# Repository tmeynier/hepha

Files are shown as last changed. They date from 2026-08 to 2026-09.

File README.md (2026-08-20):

# Hepha

TODO:

- CAD of camera holding and drawers = should finish drawers
- Check ACT policy running a lot faster
- Run flow matching
- Run VLA policy
- Try RL

"I used to fork LeRobot repository but with AI I can easily create a new repo 
with only features of LeRobot that I am interested in"

This document presents *Hepha*, a robotics project where I build and train a 
bimanual robot moving in a warehouse environment.

GIFS of the robot moving in the warehouse

GIFS of the robot moving in the greenhouse

The goals of the project are:

* Become familiar with the technologies and models used in general-purpose
  robotics (such as humanoid robots).
* Explore the challenges and current research directions in general-purpose
  robotics.
* Serve as a tutorial for readers interested in building their own robots. I
deliberately document my trials and errors to help readers understand the
challenges involved and develop an intuition for each SOTA model.

The robot consists of two parts: (1) an upper body composed of a bimanual
robot mounted on a CNC gantry system, and (2) a mobile base, similar to an
Autonomous Mobile Robot (AMR), that enables the robot to navigate throughout
the warehouse environment.

GIFS of the real upper body

GIFS of the mobile base

Most of this document focuses on the robot's upper body, covering the complete
development pipeline: mechanical design in Fusion360, 3D printing, simulation in 
Mujoco and Isaac Sim, demonstration recording for Behavioral Cloning (BC), 
policy training, RL fine-tuning, and closed-loop validation.

I also briefly discuss the robot's autonomous navigation in the warehouse,
coordination between multiple robots, and their integration into a broader
enterprise architecture. In this architecture, the robots, the ERP system, and
the Retrieval-Augmented Generation (RAG) pipeline are connected to a central
coordinator, allowing operators to control an entire fleet of robots from a
single chat interface while continuously updating the ERP and RAG according to 
the robots' actions.

For the robot's upper body, the task is the following:

> *Given a user's request, place or remove a foam cube in the correct warehouse
> drawer.*
>
> **Examples**
>
> - *Place the blue cube from the storage bin into drawer 5.*
> - *Remove the red cube from drawer 2.*
 
The task deliberately captures many of the challenges found in real-world
warehouse environments. Retrieving or placing a foam cube in a drawer
resembles storing or picking products while updating an ERP system. The same
perception, planning, and manipulation pipeline also applies to retail
(stocking supermarket shelves) and agriculture (harvesting crops in a
greenhouse). Although simplified, the techniques explored in this project
generalize to a wide range of robotic applications.

Finally, I share my perspective on the field based on my experience, discussing
the research directions I find the most promising and the challenges that still
remain.

This document was polished using AI, but I have intentionally kept
the writing simple and close to my own words.

This is not a research or survey paper, so please forgive the lack of
formalities. It is a practical project report about what I love doing.

**PS:** I made a summary video of the project here:
**TODO: Link to video**

**PS:** The project is called *Hepha*, after **Hephaestus**, the Greek god of
craftsmanship, invention, and technology.

## Table of Contents

1. [Brief Words About Me](#brief-words-about-me)
2. [Before Starting](#before-starting)
3. [Why General Purpose Robotics Is Hard](#why-general-purpose-robotics-is-hard)
4. [Pipeline Overview](#pipeline-overview)
5. [Step 1: CAD Modeling](#step-1-cad-modeling)
6. [Step 2: Simulation And Benchmark
   Policy](#step-2-simulation-and-benchmark-policy)
7. [Step 3: Real World Fine Tuning](#step-3-real-world-fine-tuning)
8. [Conclusion](#conclusion)
9. [Going Further](#going-further)
10. [Perspective](#perspective)
11. [References](#references)
12. [Citation](#citation)

## Brief Words About Me

I am a passionate machine learning engineer from Switzerland.

For the past five years I have played with robotics: Arduino, Raspberry Pi, CAD
software, CNC systems including 3D printers, servo motors and stepper motors,
actuators, radios, GSM modules, ... and many more.

I then used my machine learning background to train my own policies on the cloud and
make hardware move intelligently.

And it is so much fun, you will see.

## Before Starting

If you don't have experience in robotics yet, I recommend you to have a look at
the LeRobot project.

[LeRobot](https://huggingface.co/lerobot) is an open source project from Hugging 
Face that helps you build a 3D printed robot and run a machine learning policy on it.

**TODO:** add a GIF of my own LeRobot robot.

I also encourage you to create your own policies in LeRobot. A custom policy
that I really liked is the [DOT
policy](https://github.com/IliaLarchenko/dot_policy) from Ilia Larchenko. 

If you want to stay on your computer, without a 3D printed robot, you can also
train policies in virtual tasks, for example the PushT task trained in a Gym
environment.

**TODO:** add GIF of my PushT policy demo.

LeRobot is an amazing open source project. It has evolved from a small 
imitation learning library into one of the most complete open-source robotics 
frameworks. It contains implementations of most of the leading model 
architectures in imitation learning and reinforcement learning, ranging from ACT and 
Diffusion Policy to recent open-source Vision-Language-Action (VLA) and JEPA (Joint 
Embedding Predictive Architecture) family models.

I will mention and use some of these models: ACT, Diffusion models, VLAs, 
and V-JEPA 2. I will reuse LeRobot's dataset schema and some of its model
architectures. However, for learning purposes, I will not use the
low-code approach provided by LeRobot and instead build the models myself. 
I believe that building things yourself is one of the best ways to develop intuition 
and truly understand how things work.

### Prerequisites For This Project

1. **CAD**: familiarity with CAD software such as Fusion360, FreeCAD or
   SolidWorks.
2. **Simulation engines**: MuJoCo from DeepMind, Isaac Sim from Nvidia.
3. **ML knowledge**: imitation learning (particularly behavior cloning)
   and reinforcement learning.

## Why General Purpose Robotics Is Hard

Let me be clear: no, you cannot simply plug Claude Code, Gemini or ChatGPT into
humanoid hardware and get a fully autonomous human-looking robot.

LLMs are very good at text, but the physical world is very different from text,
and a lot more complex.

To get a sense of it, first note that for LLMs the amount of high quality
training data available is incredibly large: the internet, billions of text
examples. The space of English text to predict is relatively small: a few
thousand common words or tokens.

General purpose robotics is very different.

The inputs are images, which are much more complex to analyze than text. Possibly 
other sensor data: touch data, lidar data for depth, text, or audio
commands from a human. Basically, any input your brain receives from your body.

The output is a set of servo joint coordinates, meaning actions of the robot in
the physical world, and potentially voice if the robot should speak.

Unlike for LLMs, the amount of high quality robotics data, meaning observation data
and ground truth action pairs, is very limited.

Also unlike LLMs, where the prediction space is rather small and discrete, the
action space in robotics is continuous, and immense.

As a result, even the best LLMs will not perform well if you simply plug them
into your robot. It is also going to be very slow.

Actually, the autoregressive prediction objective that made LLMs so successful may 
not be the best way to learn representations of the physical world. Predicting every 
pixel of a future image (or reconstructing an entire image, as in an autoencoder) is 
an extremely difficult task, and much of that visual detail is irrelevant for 
decision making. 

Instead we need models capable of understanding the mapping from world 
observations to actions, and vis-versa. Models capable of learning a coherent 
embedding of the world - called *world models*. Recent work in this direction 
includes Yann LeCun's JEPA model architecture family. The idea is to predict a 
high-level representation (embedding) of missing or future information rather than 
the pixels themselves. A typical JEPA consists of:

- **Context encoder** $f_\theta$: encodes the observed part of the input.
- **Target encoder** $g_\xi$: encodes the target (for example, a future frame, a masked region, or another view).
- **Predictor** $h_\phi$: predicts the target embedding from the context embedding.

Rather than minimizing pixel reconstruction error, the model is trained so that

$$
h_\phi(f_\theta(x_{\text{context}})) \approx g_\xi(x_{\text{target}})
$$

This objective encourages the model to capture the semantic information needed to 
understand and predict the world, instead of spending capacity on reconstructing 
fine-grained visual details. LeCun recently founded [AMI Labs](https://amilabs.xyz/), 
a startup focused exactly on developing these next-generation world models.

To summarize, two important challenges of general purpose robotics are:

1. **Data**: high quality ground truth observation-action pairs.
2. **Adequate models**: models capable of understanding the world and the
surrounding physics, while still being very fast at inference. They should 
support inference at roughly 30–50 Hz, meaning the policy produces a 
new action every 20–33 ms. This is fast enough for smooth manipulation and 
good responsiveness. Slower models reduce the robot's ability to react quickly to 
changes in the environment.

### The Data Challenge

Data primarily comes from three sources:

- **Internet data** (text, images, and videos): used to train large foundation 
models on billions of examples. These models learn general-purpose representations 
of the world, although they are not optimized for a specific robot task. Their 
representations can later be adapted to robotics through models such as SmolVLA, or 
by generating synthetic robot data with systems such 
as [FLUX.3 + Mimic](https://bfl.ai/blog/flux-3-mimic).

- **Simulation data**: generated in physics simulators or even video games (FPV 
video games can be used to train humanoid robots). Simulation allows millions of 
episodes to be generated safely, quickly, and at low cost. The challenge is 
the *sim-to-real gap*: no simulator perfectly reproduces the real world. Differences 
often prevent a policy trained purely in simulation from working on a real robot. 
NVIDIA developed (Isaac Sim)[https://developer.nvidia.com/isaac] specifically 
to narrow this gap by providing highly realistic, GPU-accelerated simulations.
(MuJoCo)[https://mujoco.org] (developed by Deep Mind) serves a 
similar purpose and is widely used in robotics research. While less visually 
realistic than Isaac Sim, it is computationally much more efficient and can even run 
on CPUs, making it ideal for rapid experimentation.

- **Real robot episodes**: demonstrations collected by *teleoperating* a robot. 
During teleoperation, the robot records a sequence of observations together with the 
ground-truth actions performed by the human operator. These observation-action pairs 
form the demonstrations used for imitation learning. One common setup is a 
*leader–follower* system: the human moves a leader robot, while the follower 
robot mirrors its movements and records the data. Human can control the robot with 
game controller, a SpaceMouse, VR headsets, motion-capture gloves (e.g. [Mimic 
  Robotics](https://www.mimicrobotics.com/)), or leader–follower robot 
arms. Full-body teleoperation suits are even being developed to 
control an entire humanoid robot. Real robot demonstrations provide the 
highest-quality supervision because they capture the true dynamics, sensor noise, 
and physical interactions of the target robot. However, collecting them is slow, 
expensive, and difficult to scale to millions of episodes.

```mermaid
flowchart TD

%% =========================
%% Data Sources
%% =========================
A1["🌐 Internet"]
A2["🎮 Simulation Data"]
A3["🤖 Real Robot Episodes"]

%% =========================
%% Base Policy
%% =========================
B["Train / Fine-Tune<br/>Base Policy"]

%% =========================
%% RL Fine-Tuning
%% =========================
C["RL Fine-Tuning<br/>in Simulation Environment"]

%% =========================
%% Final Policy
%% =========================
D["Final Robot Policy"]

A1 --> B
A2 --> B
A3 --> B

B --> C
C --> D
```

## ACT advantage-weighted regression (AWR)

Hepha keeps upstream LeRobot ACT as the actor and provides a separate
`hepha_act_awr` extension. It follows ordered AWR policy iteration: collect
trajectories, fit the value head, freeze it and materialize advantages, fit ACT
with those immutable weights, collect new trajectories, merge them into the replay
dataset, and repeat. Value and actor regression never run in the same optimizer step.

For each replay transition, Hepha computes the Monte-Carlo target
`G_t = r_t + gamma * G_(t+1)`, then `A_t = G_t - V(s_t)`. Advantages are
standardized once over the replay dataset and converted to fixed weights
`min(exp(normalized_A_t / beta), awr_max_weight)`. ACT minimizes its usual per-sample
L1-plus-KL loss multiplied by that weight; transitions are still sampled uniformly.

Install the updated local entry points after pulling the repository:

```bash
.venv/bin/python -m pip install -e .
```

Collect closed-loop rollouts from the original ACT policy. All episodes are retained,
including failures, and are stored as a normal LeRobot dataset with `next.reward`
and `next.done`:

```bash
.venv/bin/hepha-awr-record models/hepha_act_200 \
  --repo-id tmeynier/hepha_act_awr_rollouts \
  --root datasets/hepha_act_awr_rollouts \
  --episodes 100 \
  --episode-seconds 100 \
  --seed-start 30000 \
  --device mps \
  --n-action-steps 1 \
  --temporal-ensemble-coeff 0.01 \
  --domain-randomization-scale 0 \
  --push-to-hub \
  --overwrite
```

The per-transition rewards are:

- `-0.001` every control step.
- `+1` the first time the selected drawer reaches 40 mm opening.
- `+3` the first time the elevated cube is stably held by both opposing pads of
  one gripper.
- `+2` the first time the cube center enters the selected drawer.
- `+5` at the terminal step when the cube is inside and the selected drawer is
  at most 5 mm open.
- `-2` when robot contact with an external object begins. Gripper/cube contact
  and selected-drawer-handle contact are allowed.
- `-0.5` when contact with the selected drawer body (excluding its handle) begins.
- `-1` when robot/floor contact begins.
- `-3` when a previously elevated cube begins touching the floor.
- `-2` when left-arm/right-arm contact begins, including the fingers.

Sustained contacts are charged once on contact onset, rather than once per frame.

Convert the original ACT checkpoint once. This copies every ACT weight exactly and
randomly initializes only the new value head:

```bash
.venv/bin/hepha-awr-init \
  models/hepha_act_200 \
  models/hepha_act_awr_init \
  --overwrite
```

Fit only the value head. ACT parameters and BatchNorm buffers remain frozen:

```bash
.venv/bin/hepha-train \
  --repo-id tmeynier/hepha_act_awr_rollouts \
  --root datasets/hepha_act_awr_rollouts \
  --policy-type hepha_act_awr \
  --policy-path models/hepha_act_awr_init \
  --output-dir outputs/hepha_act_awr_value_i0 \
  --job-name hepha_act_awr_value_i0 \
  --device cuda \
  --steps 20000 \
  --batch-size 8 \
  --num-workers 4 \
  --wandb \
  --policy-repo-id tmeynier/hepha_act_awr_value_i0 \
  -- \
  --dataset.eval_split=0.1 \
  --eval_steps=2000 \
  --policy.awr_stage=value \
  --policy.awr_discount=0.999 \
  --policy.awr_beta=1.0 \
  --policy.awr_max_weight=20 \
  --policy.value_optimizer_lr=0.0001 \
  --wandb.project=hepha
```

Freeze that checkpoint and calculate one immutable advantage and weight per replay
frame:

```bash
.venv/bin/hepha-awr-advantages \
  outputs/hepha_act_awr_value_i0/checkpoints/last/pretrained_model \
  --repo-id tmeynier/hepha_act_awr_rollouts \
  --root datasets/hepha_act_awr_rollouts \
  --output awr/iteration-000/advantages.parquet \
  --device cuda \
  --batch-size 32 \
  --num-workers 4 \
  --push-to-hub \
  --hub-repo-id tmeynier/hepha_act_awr_advantages_i0 \
  --overwrite
```

The rollout dataset, fitted value checkpoint, frozen advantage table, and actor
checkpoint are therefore all stored in separate Hugging Face repositories. A new
Pod can resume from the uploaded artifacts without access to an earlier Pod's disk.

Fit only ACT using the fixed weights. The value head remains frozen:

```bash
.venv/bin/hepha-train \
  --repo-id tmeynier/hepha_act_awr_rollouts \
  --root datasets/hepha_act_awr_rollouts \
  --policy-type hepha_act_awr \
  --policy-path outputs/hepha_act_awr_value_i0/checkpoints/last/pretrained_model \
  --output-dir outputs/hepha_act_awr_actor_i0 \
  --job-name hepha_act_awr_actor_i0 \
  --device cuda \
  --steps 100000 \
  --batch-size 8 \
  --num-workers 4 \
  --wandb \
  --policy-repo-id tmeynier/hepha_act_awr_i0 \
  -- \
  --dataset.eval_split=0.1 \
  --eval_steps=10000 \
  --policy.awr_stage=actor \
  --policy.awr_advantage_path=awr/iteration-000/advantages.parquet \
  --wandb.project=hepha
```

For the next iteration, collect fresh trajectories from the updated actor:

```bash
.venv/bin/hepha-awr-record \
  outputs/hepha_act_awr_actor_i0/checkpoints/last/pretrained_model \
  --repo-id tmeynier/hepha_act_awr_rollouts_i1 \
  --root datasets/hepha_act_awr_rollouts_i1 \
  --episodes 100 \
  --episode-seconds 100 \
  --seed-start 40000 \
  --device mps \
  --n-action-steps 1 \
  --temporal-ensemble-coeff 0.01 \
  --domain-randomization-scale 0 \
  --push-to-hub \
  --overwrite
```

Append them to a new cumulative replay dataset; the two inputs remain unchanged:

```bash
.venv/bin/hepha-awr-merge \
  --replay-repo-id tmeynier/hepha_act_awr_rollouts \
  --replay-root datasets/hepha_act_awr_rollouts \
  --new-repo-id tmeynier/hepha_act_awr_rollouts_i1 \
  --new-root datasets/hepha_act_awr_rollouts_i1 \
  --repo-id tmeynier/hepha_act_awr_replay_i1 \
  --root datasets/hepha_act_awr_replay_i1 \
  --push-to-hub \
  --overwrite
```

Run the same value, advantage, and actor stages using the iteration-1 actor as
`--policy-path`, the merged replay dataset, and new output paths. Every iteration
recomputes all returns and advantages; an old advantage file cannot silently be
used with a different replay repository.

W&B value runs report `value_loss`, `value_mean`, `return_mean`, and
`value_error_mean`. Actor runs report `actor_loss`, `advantage_mean`,
`awr_weight_mean`, and `awr_weight_max` for training and held-out evaluation.

All three sources of data are generally used together to build a strong base 
policy.

Once the base policy is trained, Isaac Sim and Mujoco provide an environment 
for RL fine-tuning. The robot can practice millions of additional interactions 
while optimizing task-specific reward functions. Examples of rewarded actions: 
successfully grasping an object, avoiding collisions, minimizing energy consumption, 
maintaining balance (for humanoids), etc.

### The Model Challenge

The research community is still divided on what the best approach for learning
world models will be.

Some believe that scaling data, model size, and compute will solve the problem. 
Of course this is the narrative of some big companies like NVIDIA, for obvious 
business reasons.

Others, including Yann LeCun, argue that simply scaling data and compute may
not be sufficient. Instead, they advocate architectures inspired by some
aspects of human cognition. Before performing an action, humans typically
reason and plan using an internal representation of the world built through
years of experience. We can mentally simulate the consequences of different
actions without physically executing them. Once a plan has been chosen,
lower-level motor control—what we often call *muscle memory*—executes it
rapidly and with little conscious reasoning.

This suggests that different levels of intelligence require different
computational mechanisms. High-level decision making involves reasoning,
planning, and predicting future outcomes, while low-level control is more
mechanical, closer to reflexes, and must operate at very high frequency.

For readers interested in this perspective, I highly recommend Yann LeCun's
lecture *A Path Towards Autonomous Machine Intelligence*. In particular,
Figure 1 provides an excellent illustration of this hierarchical view of
intelligence and world models.

There is unlikely to be a single path toward efficient world
models. Better architectures, larger and higher-quality datasets, and
increased compute will probably all contribute. The most successful systems
will likely combine advances in each of these areas.

In this project I experimented with a diverse set of methods to build my own 
opinion and understanding.

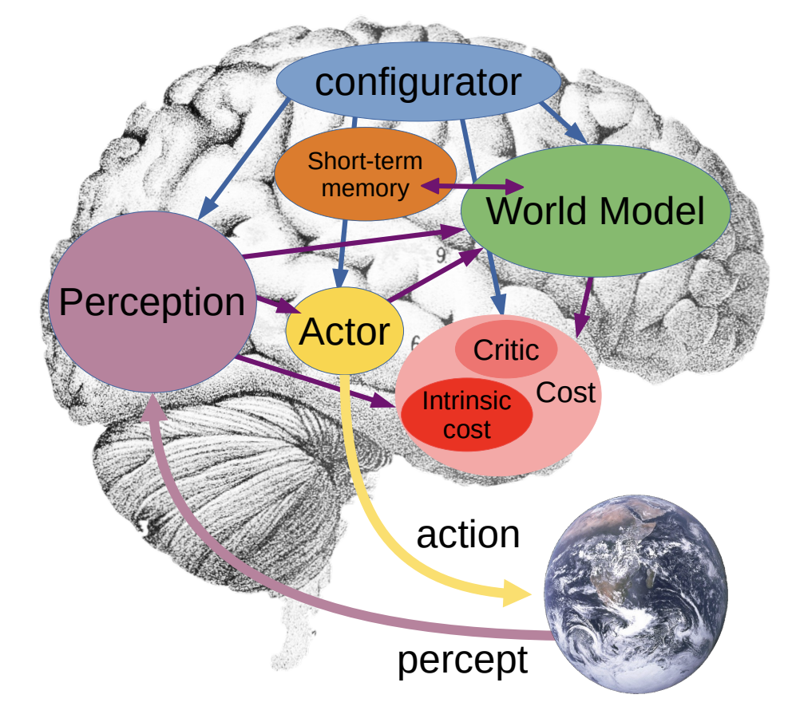
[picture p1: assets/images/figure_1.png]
Figure 1: JEPA world-model architecture


**Figure 1:** High-level architecture proposed by Yann LeCun as a foundation for
the JEPA family of world-model architectures. The perception module estimates
the current world state, the world model predicts future states under candidate
actions, the critic evaluates their expected cost, and the actor selects the
best action sequence. Short-term memory stores intermediate states, while the
configurator coordinates all modules for the current task.

## Project Pipeline

The project focuses primarily on the design and training
of the robot's upper body (the dual-arm manipulator). I will only briefly touch
on the mobile base at the end. The project pipeline is:

1. Design the robot in Fusion360.

2. Obtain a proper robot description file (URDF) from Fusion360 and use it to
   build a simulation environment (a digital twin of the real robot) in MuJoCo
   and Isaac Sim.

3. The fun part: train a base policy using imitation learning.

4. Use RL to fine-tune the base policy in the simulated environment.

Most of the work in this document focuses on step 3. Initially, all policies are
trained in MuJoCo rather than on the real robot. MuJoCo provides an excellent
playground to understand how difficult the problem really is without having to
deal with hardware issues, sensor noise, or broken parts.

Some of the intermediate steps presented here are not necessary to
obtain a working policy. I deliberately include them because they helped me
develop a much better intuition for the problem and for SOTA models.

Important concepts covered during policy training are:

* **The importance of failure recovery.** A good policy is not one that performs
  the next step well, but one that remains reliable after thousands of
  consecutive steps. Robotics is even more autoregressive than LLMs: one bad
  action at the beginning can leave the robot in a completely different state
  from the one it was trained on. Throughout the project I use *closed-loop*
  validation, where the robot executes the entire task using only the policy,
  and the final success rate is measured. Diverse data, robust models, and
  RL fine-tuning all help the policy recover from its own mistakes.

* **The challenge of embodiment.** Embodiment refers to the idea that an
  intelligent agent has a physical body through which it perceives and interacts
  with the world. ChatGPT, for example, has no body. If you connect it to a
  robot, it must learn how to control that body and interact with the
  environment. This is one of the main challenges of robotics foundation models:
  they may have been trained on many different robots, but not on *your* robot.
  Fine-tuning of the foundation model is required for the model to
  "learn" its own embodiment. I intentionally designed a robot with 15 degrees
  of freedom that does not resemble existing robots, making embodiment a relevant 
  challenge.

* **The multimodality problem.** A single observation can correspond
  to many valid actions - e.g. an object can be picked from the left or
  from the right. If the training data contains both strategies, a traditional
  regression model may predict their average—which could be an invalid action. 
  Policies should learn a distribution over possible actions given an observation,
  $p(a \mid o)$, rather than predicting a single deterministic action. Gen AI 
  can be a solution. Target distribution that have different modes.For example a 
  simple MSE would optimize to predict the mean of the data. MAE is lot better 
  than MSE. VQ-BeT avoids this by turning continuous actions into discrete tokens, much
like language models turn text into tokens.Because classification solves the 
  problem = this naturally models multiple valid behaviors.
Unlike ACT, there is no CVAE latent variable.
Unlike Diffusion Policy, there is no denoising process. Diffusion model the whole 
  distribution rather than doing point prediction.
Diffusion: "Learn how to gradually remove noise."
Flow Matching: "Learn the velocity field that transports noise into data."
Robot when predicting chunks can go left then right, left then right, .... Realt 
  Time Action Chunking with Large Models

* **The importance of planning horizon.** Predicting a chunk of future actions
  is more effective than predicting only the next action. A robot must
  understand not only where it should move, but also the intended motion,
  velocity, and trajectory. These are better captured when the model predicts a
  sequence of future actions.
The action distribution in robotics versus LLMs is very different: actions are 
  very correlated, sometimes sequence of actions that are the same, etc. Which 
  might make the model always predict the same action.

* **The importance of inference speed.** A larger model may achieve higher
  accuracy, but it is of little practical use if it cannot run at the required
  control frequency. Large models are well suited for high-level reasoning and
  long-term planning, while smaller models excel at fast, reactive control.
  Combining both often provides the best trade-off.
System 1 and system 2 from Daniel Kahneman. See Gemini Robotics paper from Google 
  or Pi0.5 from Physicall Intelligence or Gr00t model from Nvidia.
Real word manipulation and embodiment data would be great new data for LLMs.

Now the robot reaches a state that was never present in the training dataset.

The policy doesn't know what to do there.

It makes another mistake → gets even further away → makes another mistake.

This is called distribution shift or compounding errors.

Only RL can beat the expert, because it optmizes for it.

Show the pyramid of robot data to show your reasoning

Data augmentation — general umbrella term. You modify observations/actions while preserving the intended behavior: camera noise, lighting changes, object-position variations, action noise, etc.
Trajectory perturbation / demonstration perturbation — specifically perturbing expert trajectories to expose the policy to imperfect states.
Domain randomization — randomizing the simulation/environment: textures, lighting, camera pose, friction, masses, object positions, etc. Primarily useful for robustness and sim-to-real.
Noise injection — explicitly adding noise to states, observations, or actions.
Recovery data / recovery demonstrations — particularly important for BC: deliberately move the robot away from the perfect expert trajectory and provide the correct action to recover.
DAgger — goes further: run the learned policy, let it reach states that the expert dataset didn't contain, then have an expert label the correct actions for those states.

### Robot Description (Upper Body)

The robot's upper body has 15 Degrees of Freedom (DoF): three linear axes
(x, y, and z) provided by the CNC gantry, and two 6-DoF robotic arms.

The CNC gantry is equipped with closed-loop servo motors that I reused from 
another personal project. It allows the robot to move its arms between different 
work areas: closer to the collector or closer to the warehouse shelves.

**TODO:** add two images of the robot in two work position

### Task Description (Upper Body)

As mentioned earlier, the task is: 

> *Given a user's request, place or remove a foam cube in the correct warehouse
> drawer.*

The task resembles a realistic robot task in a warehouse-like environment. I call 
*warehouse-like environment* any environment composed of zones where
robots maneuver and zones where products are stored, placed, or picked from.
Examples are traditional warehouses, supermarkets, pharmacies, greenhouses, or
even vineyards.

The robot would navigate in the environment and use its arms to place
objects into storage, or remove objects from storage.

I will not discuss autonomous navigation in the warehouse-like environment, as this 
does not necessarily require a ML model. If you are curious, the real robot base for 
navigation looks like this (it should use omniwheels in some settings or 
mechanical wheels):

**TODO:** add GIFS of the robot base moving

In humanoid robot design, not using legs but an Autonomous Mobile Robot (AMR) is 
an approach also taken by [Genesis AI](https://www.genesis.ai/). It greatly 
simplifies the problem while preserving most of the robot's capabilities.

**TODO:** add GIFS of Genesis AI robot

TODO: mention about the complexity of the task: not always fetch the cube or open 
drawer with the same hand, hand collaboration, moving in the right direction with 
respect to hand 1 or 2, etc.

## Step 1: Model The Robot CAD

First, I construct the 3D model of the robot.

This is required to validate the design, 3D print the robot, and build the
simulation environment in MuJoCo and Isaac Sim.

I use [Fusion360](https://www.autodesk.com/products/fusion-360/overview).

The path to the CAD project is **TODO**.

Each component is modeled as an assembly, possibly made of several
subcomponents:

```text
hepha-robot-cad
├── base
├── cnc_x
├── cnc_y
├── shoulder_l
├── shoulder_r
├── head
├── forearm_l
├── forearm_r
├── arm_l
├── arm_r
├── wrist_l
├── wrist_r
├── hand_l
├── hand_r
├── finger_l
├── finger_r
├── storage_rack
└── storage_bin
```

The structure of the Fusion360 assembly is very important because the
requirements for 3D printing and URDF export are different.

* Rule 1 (3D printing): each physical part should be its own assembly
  (although your assembly can be nested to keep the project organized). It's
  the conventional structure used in CAD projects, as shown above.

* Rule 2 (URDF export): the assembly hierarchy must instead follow the
  robot's kinematic tree: each movable link should be represented by a
  separate assembly. For example, the left shoulder link is one assembly, the
  left upper arm another, and so on, connected by revolute or linear joints.
  I describe this structure in the next section.

Because these two hierarchies serve different purposes and are organized 
differently, I maintain two separate Fusion360 projects.

**TODO:** add GIF of the CAD.

The robot components were 3D printed and assembled, for both the leader and follower.
Since I do not have a CNC machine for the leader, I used a controller to
lead the CNC follower.

**TODO:** add GIF of the real robot with the leader and follower.

## Step 2: Build The Simulation Environment

Tell that you used IK to see if everything works in the environment.

Building a simulation environment with a digital twin of the robot is essential 
to validate the hardware and train RL policies. I will try both MuJoCo and Isaac Sim 
and compare the two.

### From CAD to URDF

To create a robot description file that can be used by simulators, I use the
Fusion360 plugin `ACDC4Robotics` to convert the CAD model into a `.urdf` file.
A `.urdf` file describes the robot: it contains not only the visual meshes of
its components, but also the joints between them, inertial properties, centers
of mass, friction parameters, and other information required to build a
realistic simulation.

To use `ACDC4Robotics`, I had to transform my original
`hepha-robot-cad` project into a new project called `hepha-robot-sim`.
You can find it at **TODO:** add path.

In the CAD project, components are organized as physical robot parts. In the
simulation project, they must instead follow the robot's kinematic tree: one
component per **link**, with exactly one body inside each link component.

```text
hepha-robot-sim
├── cnc_x_link
├── cnc_y_link
├── shoulder_l_link
├── shoulder_r_link
├── forearm_l_link
├── forearm_r_link
├── arm_l_link
├── arm_r_link
├── wrist_l_link
├── wrist_r_link
├── hand_l_link
├── hand_r_link
├── finger_l_link
├── finger_r_link
├── drawer_1_link
├── drawer_2_link
├── drawer_3_link
├── drawer_4_link
├── drawer_5_link
├── drawer_6_link
├── drawer_7_link
├── drawer_8_link
├── drawer_9_link
└── head_link
```

To create this new hierarchy, I first created an empty component for every
link. I then copied the relevant bodies into their corresponding link
components, combined them into a single body using Fusion360's `combine` tool,
and finally created the joints between the links (`revolute` or `slider`).

**TODO**: GIFS of the simulated robot

### MuJoCo

MuJoCo is one of the most widely used physics simulators in robotics research.
It is easy to install, has a relatively low learning curve, and is
computationally efficient while still providing accurate physics simulation.
Unlike Isaac Sim, MuJoCo runs well on a local machine without requiring a GPU.
Its main drawback is that it does not produce photorealistic renderings, which
can be important for vision-based robot policies (like for humanoid robots).

The `.urdf` file generated in the previous section only defines the robot's
visual meshes and joints. Since visual meshes are only used for rendering, I
also needed to define collision geometries to obtain a physically realistic
simulation.

MuJoCo's physics engine relies on simple primitive geometries (boxes, spheres,
cylinders, etc.) for collision detection, as they are much faster and more
numerically stable than arbitrary triangle meshes. For each link in my
`hepha-robot-sim` project, I therefore created a simplified `.step` file made
only of primitive boxes. I then wrote a small Python script to convert these
files into the corresponding MJCF collision geometries.

Finally, I ensured that the robot had realistic joint limits, centers of mass,
and inertia before running the simulation.

**TODO:** add path to the collision `.step` files.

**TODO:** add path to the final `.urdf` file.

**TODO:** add GIF showing the collision geometries.

### Isaac Sim

## Step 3: Base Policy Training

First, define the metrics

- importance of failure recovery: act on simplified data + importance of planning 
  horizon with act
- challenge of embodiment: explain how to fine tune the foundation model + 
  importance of inference speed

ACT simple

Foundation simple

Act random

Diffusion random

Foundation 0 random 

Foundation 1 random

With BC real robot

RL fine tuning 

Final demo

metrics: closed loop validation, achievement: grasped cube, ...

## Step 4: RL Fine Tuning

#### Collision Geometries

#### Recording Episodes In Simulation

Now that I have a somewhat realistic digital twin of the robot, I can set things
up to record virtual episodes of the robot doing the task. Three methods can be
used to record episodes in the simulated environment:

1. use a controller,
2. use a physical leader,
3. use inverse kinematics, IK.

IK allows to compute the joint movements required to place the end effector, the
robot hand with the gripper, in a target position. When used several times, it
allows to artificially create a robot movement. For example, I can decompose the
movement "grab the cube and place it into the drawer" into smaller targets:
"place the hand in grab position", "close the hand", "move the hand above the
drawer", and "open the hand".

With this technique, the overall movement of the robot is not very natural or
flexible. For example, if the cube falls out of the hand, the robot will not
re-fetch it and will continue the movement without the cube. But IK makes it
possible to create a large set of episodes, which can be used to train a
benchmark policy and fine tune it later with higher quality data.

Recording using a controller or a physical leader is on the other hand time
consuming, so I decided to use IK first to train a benchmark policy. I will use
the physical leader and controller later to fine tune the policy.

Starting from a strong benchmark policy is especially important for RL because
it dramatically reduces exploration. It allows the agent to refine an already
competent behavior instead of wasting time discovering basic skills from
scratch.

**TODO:** add GIF of episodes.

Before the start of each episode, I randomize the position and orientation of
the cube, the colors of the geometries, and add a bit of noise to the camera
position and orientation between episodes for better generalization.

Episodes are stored as a Hugging Face dataset using LeRobot's dataset format,
also used by Nvidia and many robotics companies.

#### Training The Policy

In this section I will use the simulated data from MuJoCo to train a base
Behavior Cloning (BC) policy.

Thanks to IK, I was able to produce thousands of episodes while trying to add
some randomization to each episode. IK is not sufficient to build a strong
policy and is only meant to obtain a benchmark policy. Imagine something unseen
during training happens, for example the cube drops from the hand, or some
drawers are randomly opened. Then the policy will likely fail because IK
recorded episodes strongly lack natural randomness.

BC is a specific Imitation Learning (IL) method that learns a direct mapping
from observations to actions using supervised learning. IL is the broader field
of learning behaviors from demonstrations, including BC and more advanced
methods such as inverse reinforcement learning and DAgger (Dataset Aggregation).

I will explore several BC methods, from standard models to foundation models. I
summarize each model in one sentence and invite the reader to ask its favorite
AI model to learn more:

- **ACT, Action Chunking Transformer:** predicts a sequence of future actions at
  once using a Transformer, producing
smoother and more stable robot trajectories than single-action prediction.
- **Diffusion Policy:** generates robot actions through an iterative denoising
  process, allowing it to model multiple
valid behaviors and produce robust, high-quality motions.

I will also explore more complex models to open the work.

- **Vision-Language-Action models:** learn a policy conditioned on visual
observations, robot state, and natural language instructions, enabling a single
model to perform many different tasks. In this project, VLA takes as input the
task request prompted by the user like "place the red cube in the upper left
drawer" or "remove the cube from the lower right corner".

- **VLA-JEPA, World Models:** learn predictive latent representations of future
  world states, allowing the robot to
reason about possible action consequences in latent space before acting, instead
of only imitating demonstrations directly.

By exploring models with fundamentally different learning paradigms, I aim to
give you (and myself) a broader understanding of modern robot learning
approaches, with their respective strengths and limitations.

My dataset is made of 1000 generated episodes of around 60 seconds each, split
90%-10% between train and test.

The policies were trained for up to 100 epochs with early stopping, on an NVIDIA
RTX 5090 GPU with 32 GB VRAM, 60 GB RAM, and 15 vCPUs.

##### ACT

# TODO: add paper summary at the beginning

ACT addresses a related problem from a different angle.

Instead of:

observation → next action

ACT predicts a chunk of future actions:

observation_t ↓ Transformer ↓ [a_t, a_t+1, a_t+2, ... a_t+k]

Why?

Because predicting individual actions at high frequency makes errors accumulate
and can produce jittery behavior.

###### Training

**TODO** add some weight and bias plots to show how many steps + how ofter
validation and checkpoints are saved.

**TODO:** add training command.

**TODO:** add Hugging Face model and dataset link.

**TODO:** add Weights & Biases link.

###### Metrics

| Metric | Value |
| --- | --- |
| Success Rate (%) | TODO |
| Action Error (L1 / MSE / MAE) | TODO |
| Collision Rate | TODO |
| Inference Speed (Hz or ms/action) | TODO |
| Number of Demonstrations | TODO |

###### Qualitative Results

**TODO:** add test ground truth GIF.

**TODO:** add test predicted GIF.

##### Diffusion Policy

But robot behavior is often multimodal.

Imagine grabbing a cup. You could approach it:

← from left

or

from right →

A regression model trained with MSE can effectively average different valid
demonstrations, potentially producing an action that corresponds to neither
strategy. Diffusion Policy instead learns a distribution over action sequences:

###### Training

**TODO:** add training command.

**TODO:** add Hugging Face model and dataset link.

**TODO:** add Weights & Biases link.

###### Metrics

| Metric | Value |
| --- | --- |
| Success Rate (%) | TODO |
| Action Error (L1 / MSE / MAE) | TODO |
| Collision Rate | TODO |
| Inference Speed (Hz or ms/action) | TODO |
| Number of Demonstrations | TODO |

###### Qualitative Results

**TODO:** add test ground truth GIF.

**TODO:** add test predicted GIF.

##### Vision-Language-Action (VLA)

###### Training

**TODO:** add training command.

**TODO:** add Hugging Face model and dataset link.

**TODO:** add Weights & Biases link.

###### Metrics

| Metric | Value |
| --- | --- |
| Success Rate (%) | TODO |
| Action Error (L1 / MSE / MAE) | TODO |
| Collision Rate | TODO |
| Inference Speed (Hz or ms/action) | TODO |
| Number of Demonstrations | TODO |

###### Qualitative Results

**TODO:** add test ground truth GIF.

**TODO:** add test predicted GIF.

##### VLA-JEPA

###### Training

**TODO:** add training command.

**TODO:** add Hugging Face model and dataset link.

**TODO:** add Weights & Biases link.

###### Metrics

| Metric | Value |
| --- | --- |
| Success Rate (%) | TODO |
| Action Error (L1 / MSE / MAE) | TODO |
| Collision Rate | TODO |
| Inference Speed (Hz or ms/action) | TODO |
| Number of Demonstrations | TODO |

###### Qualitative Results

**TODO:** add test ground truth GIF.

**TODO:** add test predicted GIF.

#### Fine Tune The Policy Using RL

Reinforcement Learning (RL) is a subset of machine learning where a policy
learns by doing actions in an environment and getting rewards from these
actions. In the RL setup, the robot is usually called the agent. It explores the
environment, tries actions, receives rewards, and updates its policy based on
what worked or not. With this setup, it is easy to see why RL is interesting for
robotics: robots also learn by acting in a physical or simulated world.

However, using RL directly in the real world can be dangerous and inefficient.
Imagine asking a humanoid robot to learn walking from scratch with an untrained
policy. It would perform random actions for a long time before mastering the
movement, and the hardware, or even the environment around it, could be damaged.
Another difficulty is reward design. For example, what should the reward for
walking be? "Stay upright and move in all directions" sounds reasonable, but a
robot could achieve this reward in a strange way without really learning a
natural walking behavior.

This is why RL is often more useful for fine tuning in robotics. The robot
should already have a strong benchmark policy, so it can explore safely and only
improve what still needs adjustment. For example, a humanoid robot that already
knows how to walk and avoid collisions could use RL to refine its behavior for a
more specific objective. RL can also help the robot adapt on the fly: if it
encounters new situations and collides with objects, the policy can be fine
tuned to avoid these failures in the future, a bit like humans learn from
experience.

In this project, I use RL after each BC policy is trained. The goal is not to
learn the whole task from scratch, but to update the policy and make the
movements safer and smoother. For example, RL can help prevent self-collisions,
such as the left and right arms colliding with each other.

I will use Proximal Policy Optimization (PPO), which is very commonly used in
robotics. With PPO, I can train the policy by simulating many robots in
parallel, all collecting experience and updating the same policy. So in MuJoCo,
I simulate **TODO: number of robots** robots in parallel. Each robot, or agent,
starts from the benchmark policy, and the policy is then fine tuned through PPO.
The simulations are run on **TODO: GPU specs, same as before**.

**TODO:** describe some mock specs and results.

**TODO:** add GIF of all robots in MuJoCo simulation.

#### Conclusion On Mujoco's Benchmark Policy

### Isaac Sim - Isaac Lab

#### Recording The Episodes In Isaac Sim

#### Training The Policy

##### ACT

###### Training

**TODO:** add training command.

**TODO:** add Hugging Face model and dataset link.

**TODO:** add Weights & Biases link.

###### Metrics

| Metric | Value |
| --- | --- |
| Success Rate (%) | TODO |
| Action Error (L1 / MSE / MAE) | TODO |
| Collision Rate | TODO |
| Inference Speed (Hz or ms/action) | TODO |
| Number of Demonstrations | TODO |

###### Qualitative Results

**TODO:** add test ground truth GIF.

**TODO:** add test predicted GIF.

##### Diffusion Policy

###### Training

**TODO:** add training command.

**TODO:** add Hugging Face model and dataset link.

**TODO:** add Weights & Biases link.

###### Metrics

| Metric | Value |
| --- | --- |
| Success Rate (%) | TODO |
| Action Error (L1 / MSE / MAE) | TODO |
| Collision Rate | TODO |
| Inference Speed (Hz or ms/action) | TODO |
| Number of Demonstrations | TODO |

###### Qualitative Results

**TODO:** add test ground truth GIF.

**TODO:** add test predicted GIF.

##### Vision-Language-Action (VLA)

###### Training

**TODO:** add training command.

**TODO:** add Hugging Face model and dataset link.

**TODO:** add Weights & Biases link.

###### Metrics

| Metric | Value |
| --- | --- |
| Success Rate (%) | TODO |
| Action Error (L1 / MSE / MAE) | TODO |
| Collision Rate | TODO |
| Inference Speed (Hz or ms/action) | TODO |
| Number of Demonstrations | TODO |

###### Qualitative Results

**TODO:** add test ground truth GIF.

**TODO:** add test predicted GIF.

##### VLA-JEPA

###### Training

**TODO:** add training command.

**TODO:** add Hugging Face model and dataset link.

**TODO:** add Weights & Biases link.

###### Metrics

| Metric | Value |
| --- | --- |
| Success Rate (%) | TODO |
| Action Error (L1 / MSE / MAE) | TODO |
| Collision Rate | TODO |
| Inference Speed (Hz or ms/action) | TODO |
| Number of Demonstrations | TODO |

###### Qualitative Results

**TODO:** add test ground truth GIF.

**TODO:** add test predicted GIF.

#### Fine Tune The Policy Using RL

#### Conclusion On Isaac Sim & Lab Benchmark Policy

## Step 3: Real World Fine Tuning

#### Recording Real World Episodes

#### Fine Tune The Policy

Use real world episodes + RL

## Conclusion

One advantage of simulation = smaller model

## Going Further

Maybe for a next video: the project Hepha for companies with warehouse-type
environments.

Combine with chatbot, query builder, and RAG.

## Perspective

I think this is a very special moment for AI and robotics. During the last few
years, researchers managed to train smart models on text, images, and audio.
This is remarkable, especially because these models never learned directly from
the physical world. They learned about water and fire from internet data, but
they never drank a cup of water, jumped into a lake, or burned themselves.
Humans learn a large part of intelligence from these experiences. If a person
only learned life from textbooks, without ever touching, moving, falling,
carrying, or feeling anything, I doubt this person would develop the same
intelligence as everyone else.

If models could interact with the physical world, the learning signal would
become much richer. A brain without a body is limited. The body gives the brain
an enormous amount of data every second: vision, hearing, touch, smell, taste,
temperature, proprioception, balance, pain, interoception, etc. Current AI
models can show impressive intelligence while still failing at basic physical
tasks. This is not surprising: models have had more access to quantum physics
books than to data about how to drink a cup of water.

The race to give AI a body has started. Hardware has become more complex, and
robots are becoming more capable. This is visible in videos from Figure AI,
Genesis AI, or Tesla Optimus. At the same time, society needs to prepare
carefully. Jobs will change. The quantity of compute required to train and run
these systems is staggering, so the environmental impact also matters. The
prospects are very interesting, but also worrying if misused.

Still, it is important not to get ahead of ourselves. As explained in this
report, the complexity of the physical world is nowhere close to the complexity
of well formatted and bounded text data, or even image and audio data. Industry
is progressing fast, but humanoid robots are not in homes yet. The models and
setups are still very specific to each task. It is already much better than the
old "if this, then that" robotics logic, but it is still not one model fits all
like with LLMs.

My view is that the biggest issue is data. With good quality data, research in
model architecture becomes easier and will follow more naturally. One solution
is simulation: scan the world, recreate every object digitally in 3D using AI,
and give each object realistic physical properties. Highly realistic simulation
would allow training benchmark policies for humanoid robots before safely
rolling them out in the physical world.

Then, as done in this report, a basic benchmark policy trained on simulated data
can be used to roll out a humanoid robot more safely in the physical world. The
first humanoid robots people see will probably not be very smart, or even very
useful. But they will collect crucial real world data to make the next
generation of robots smarter, similar to what Tesla cars do today for autonomous
driving. This can become a positive loop: the more people buy robots, the
smarter the robots become; and the smarter the robots become, the more people
buy them. VAM are a good way to also learn a world model. The exact BERT
architecture matters less today than the paradigm it helped establish:

large-scale pretraining → general representation → downstream adaptation
Transferring this philosophy to physical embodiment—through
Vision-Language-Action (VLA) models like RT-2, PaLM-E, OpenVLA, and
VoxPoser—unlocks physical zero-shot and few-shot behaviors: This helped
establish the modern foundation-model / scaling paradigm:

Train one enormous general model → prompt it to perform many different tasks.

That philosophy is increasingly being transferred to robotics.

RT-2: Vision-Language-Action Models Transfer Web Knowledge to Robotic Control:
This paper helped establish what we now call Vision-Language-Action (VLA)
models. It demonstrated that knowledge learned from Internet-scale
vision/language data could improve robotic generalization and semantic
reasoning.

An entirely new industry will likely rise around this. Compute will need to
become more efficient, maybe with quantum computing one day. Hardware will
become more precise. Models will become smarter and better adapted to
understanding the physical world and mapping observations to actions. Real-world
deployment sets a hard constraint: the model has to act as fast as the world
moves.

These new models will not only be useful for humanoid robots. If they can
understand the physical world better than current models, they could become
useful for many other applications too: autonomous cars, aircraft, physics
research, chemistry, and probably many fields I cannot even imagine yet. They
may even go beyond human intuition in some cases. For example, if you throw a
ball in the air, a strong world model could predict not only where it will land,
but also its speed, its temperature change, and many other physical details that
humans do not naturally estimate.

There is a need to large scale open source datasets for robot for large
pretraining robot foundation-model idea. RT-X models are robot foundation models
trained on data from many different robots, tasks, and institutions, rather than
one model trained only on one robot.

This is strategically important because robotics has a data problem. There is no
robotics equivalent of the entire Internet.

The data story is particularly compelling

This also relates directly to your earlier Street View idea.

You don't necessarily need robot data to learn all parts of the model.

You could pretrain spatial understanding from enormous passive datasets:

multi-view images + video→3D spatial representation

Then learn generic dynamics from video:

Z t 3D 

→Z t+1 3D 

Then use the much scarcer robot datasets to learn action-conditioned dynamics:

(Z t 3D 

,a t 

)→Z t+1 3D 

This matters because robot demonstrations are expensive, while images and videos
are essentially unlimited.

BILLIONS OF IMAGES / VIDEOS ↓ learn geometry + objects + semantics ↓ 3D WORLD
MODEL ↓ MILLIONS OF ROBOT TRAJECTORIES ↓ learn action → physical consequence ↓
ACTION-CONDITIONED 3D WORLD MODEL ↓ thousands of demonstrations for your
specific robot ↓ ROBOT POLICY

Yes, absolutely. Video game data—especially footage of real people playing
games—is currently one of the primary sources used to pre-train world models and
foundation models for robotics

DeepMind trained Genie on 200,000+ hours of unlabelled 2D platformer gameplay
videos.

goal = zero-shot generalization Fei-Fei Li’s World Labs

I do not believe in full zero shot learning

world models are heavily accelerating the development of autonomous vehicles
(AVs). Platforms like NVIDIA's Cosmos world foundation model are built
specifically to handle both general robotics and autonomous driving

https://marble.worldlabs.ai/

Studying this field also makes us appreciate the complexity of the human brain
and the body. Both are masterpieces of engineering from nature. No physical law
prevents humans from copying parts of this artificially, and this may happen
sooner or later. Maybe it takes 30 years, maybe 100 years.

## Future Work

## References

This section is still a work in progress.

See [references/README.md](references/README.md).

## Citation

- The trajectory problem
- The importance of failure, so RL
- The autoregressive failure: the importance of closed loop simulation and testing
- The importance of embodiment
- big model and small model
- The challenge of zero shot learning
- The importance of inference speed
- Discuss all metrics that are generally used in robotics to access the goodness
of a policy (closed loop validation)

I purposely made the robot different than traditional robot in order to test
embodiment (make embodiment more challenging).

Because Diffusion Policy learns a score function (gradient field) over the
action space rather than a direct mapping, it is significantly better at
recovering from unexpected physical bumps, obstacles, or displaced objects
mid-task.

Because every robot has a different physical body (kinematics, arm length,
gripper type, joint limits) and camera setup (angles, focal lengths, lighting),
deploying these models zero-shot on an unseen robot is very difficult and
usually fails.  1. Do people actually use them "Zero-Shot"?Rarely in practice.
Zero-shot transfer (placing a model directly onto a totally new robot with zero
extra training) is still an open research challenge.

When people say a model is a "Generalist" or "Zero-Shot," it usually means
zero-shot for new objects, new locations, or new natural language instructions
on a robot body the model has already seen during pretraining.

What works Zero-Shot: Handing the model a new item (e.g., "pick up the purple
dinosaur toy") on a standard arm it was trained on (like a Franka Emika Panda or
Aloha dual-arm).  What breaks Zero-Shot: Putting the model on a different
hardware setup. If your camera is mounted 15 cm lower, or your gripper moves at
a different speed, zero-shot performance drops significantly.

If you have a robot that wasn't in the training set (e.g., a custom UR5, xArm,
or custom 3D-printed arm), you don't use the model zero-shot. Instead, you use
Few-Shot Fine-Tuning. Like what is done between Dark Forest Labs and Mimic!

Neither should be considered truly Hepha-compatible zero-shot until an
embodiment adapter is trained.

hepha_act_100_simple_drawer_5: 82 episodes with 500 tentatives Total 100 episode
for 646 attends

Now that I went through the project overview and the main challenges of general
purpose robotics, let's deep dive into the project:

Video Pre-Training (VLA Models): Pre-train a Vision-Language-Action (VLA) model
or World Action Model (WAM) on internet-scale video datasets (including human
everyday videos and video game play logs). This establishes spatial "common
sense," visual scene understanding, and motion priors.

The safer one is residual RL: final_action = frozen_bc_policy(obs) +
rl_residual(obs) So ACT/Diffusion gives a reasonable behavior prior, and PPO
only learns corrections. Behavioral Cloning (BC) almost always happens BEFORE
Reinforcement Learning (RL).

In standard robotics and simulation pipelines, BC acts as the pre-training
(warm-start) phase, while RL acts as the fine-tuning phase. Residual RL: A
pre-trained BC network outputs a base action, while a smaller RL network runs
concurrently to learn an additive "correction" offset
($\mathbf{a}_{\text{final}} = \mathbf{a}_{\text{BC}} + \mathbf{a}_{\text{RL}}$).

It’s easy to look at recent advances in Vision-Language-Action (VLA) models and
Diffusion Policies and think, "If the AI can observe human demos and clone them
directly, why do we still need physics engines like MuJoCo or Isaac Sim?"

The short answer: A foundation model + BC dataset can teach a robot what to do,
but without a simulation engine, it has no safe place to learn how not to fail.

Pure BC is inherently open-loop imitation. A simulation engine provides the
closed-loop feedback, safety sandbox, and synthetic scaling necessary to turn an
brittle demo mimic into a reliable industrial policy.

In a BC dataset, human teleoperators almost always perform the task
successfully. They rarely show the robot:

What to do if its hand slips off an object halfway through a grasp.

How to recover if its foot slides 2 centimeters on a slick floor.

How to stabilize itself after a sudden external bump.

Because the policy only saw pristine trajectories during BC, a tiny 1% tracking
error in frame 10 shifts the robot into an unfamiliar state. In frame 11, it
makes a bigger error, and by frame 20, it drifts completely off course or
crashes.

Where Simulation Fits In: You put the BC policy inside a physics simulation,
intentionally knock it around with random forces, and let RL teach the robot
error-recovery behaviors across millions of failure cases—without damaging a
$150, 000 real-world robot. + Infinite Data Augmentations (Domain
Randomization). Collecting 500 real-world teleop demonstrations takes weeks of
human effort.

Simulation scales your modest BC dataset into millions of extreme edge-case
variations overnight.

Real-Time Execution Speed (Simulation as a Safety Guardrail) Large foundation
models are computationally heavy. Running an 8-Billion parameter VLA model
directly in an end-to-end control loop on onboard edge compute often yields low
update rates (e.g., 5 Hz to 10 Hz).

A humanoid balancing or manipulating delicate objects requires high-frequency
control loops (100 Hz to 1,000 Hz).

The SOTA Setup: The Foundation Model / BC policy runs slowly in the background,
outputting high-level spatial targets at 5 Hz.

The Sim-Trained RL / Controller: A lightweight policy (trained in simulation)
runs onboard at 500 Hz, consuming those spatial targets and maintaining
instantaneous dynamic balance and torque regulation.

Pretrained Backbone: You download a model like OpenVLA or Octo. It already
understands what a "cup" looks like, what "pick up" means, and basic
physics/spatial awareness from being trained on ~1,000,000 robot trajectories
(e.g., the Open X-Embodiment dataset).  Collect 10 to 50 Teleoperated Demos: You
use a VR controller, leader-follower arm, or space-mouse to teleoperate your
specific robot doing a task 20–50 times while recording camera feeds and your
robot's exact joint angles.Parameter-Efficient Fine-Tuning (LoRA): Instead of
training the entire 7-billion-parameter model from scratch, you freeze the model
and train a small "adapter" (LoRA).  Result: In 15–30 minutes of training on a
single GPU, the model adapts its spatial understanding to your exact camera
placement, lens distortion, and motor response.

Cross-embodiment adaptation is one of the purposes of VLA fine-tuning.

Google Deep Mind Gemini Robotics 2

Genie (Generative Interactive Environments)

PEFT means Parameter-Efficient Fine-Tuning. pipeline uses LoRA, a common PEFT
method

DDPM: discrete probabilistic denoising steps usually predicts noise or clean
samples

Flow matching: learns a continuous velocity field integrates an ODE from noise
to actions

low matching often needs fewer inference iterations. SmolVLA uses this to
generate action chunks efficiently.

Pretrained SmolVLA vision-language understanding temporal action generation
original 6D embodiment interface │ ▼ Replace/reconfigure embodiment interface
for 15D Hepha data │ ▼ Fine-tune action expert with LoRA Fully train
state/action projection layers │ ▼ 15D Hepha SmolVLA policy

Flow matching is a generative method that teaches the policy how to transform
random noise into a meaningful action sequence.

Summarize my journey in robotics, discovering the different challenges of AI
applied to robotics:

With simple BC you get out what you get in: no generalization. IK in purpose to
show how a "perfect" training data is not suited. The policy simple learn the
body of the robot and how to make one step right. It knows nothing about long
term and horizon or the environment. To draw a similar cmoparison

Before the era of Large Language Models (LLMs), Artificial Intelligence in
Natural Language Processing (NLP) relied almost entirely on task-specific models
(narrow AI). If you wanted a system to generate poetry, write SQL queries, or
translate French, you had to design or train separate models for each task using
small, specialized datasets. A narrow model trained only on a dataset of 50,000
poems learns isolated structural patterns (rhyme, meter, line breaks). However,
it lacks a deeper understanding of the world, history, emotional nuance, or
cross-domain metaphors. The Rule-Based & Statistical Era (1950s – Early 2010s)
Task-Specific Neural Networks (2013 – 2016) The Architecture Breakthrough &
Pre-training (2017 – 2018) However, to use BERT for a specific task (like
sentiment analysis or named entity recognition), developers still had to attach
a custom task head and fine-tune it on labeled data for that exact task. The
Shift to Generalist Foundation Models (2018 – Present) OpenAI shifted to
autoregressive models (decoder-only) focused on predicting the next word. With
GPT-2 (1.5 billion parameters), researchers noticed an unexpected behavior: when
a model gets large enough and is trained on enough web data, it can perform
translation, summarization, and question-answering without any task-specific
fine-tuning (zero-shot transfer).

Make a comparison diagram between LLMs and robotics

1. Failing is important: deterministic versus noise, world model versus simple
   BC
2. ACT verus diffusion: choose the right path? But ACT also

Like when you loose an arm, there is a period of adapation, embodiment, you have
to train: this is RL. Your perseption of the world does not change, but your
body did (your world model does not change).

One thing that might stay in the pipeline that is not in LLMs is the RL
simulation fine tuning / embodiment.

Embodiment is the principle that intelligence, cognition, and learning do not
happen in an isolated digital void; they emerge from the continuous interaction
between an agent, its physical or simulated body, and its environment.

Hepha is a substantial embodiment change. SmolVLA was not primarily pretrained
on this dual-arm gantry configuration. The vision-language backbone can transfer
object and task understanding, but the 15D coordinated motion must mostly be
learned from your demonstrations. LoRA is a good baseline, not guaranteed to be
optimal. For a dramatically different body, I would compare: Current
configuration: LoRA on the expert and state/action projections. Stronger
adaptation: LoRA on the VLA, but fully train state_proj, action_in_proj,
action_out_proj, and action-time projections. Full fine-tuning, if GPU memory
permits. The official LeRobot interface supports fully training selected modules
with --peft.full_training_modules. That experiment is especially relevant for
Hepha.

Pretrained VLA ↓ Target-robot demonstrations (images + language + robot state +
actions) ↓ Adapt state/action projections to the new robot ↓ LoRA or full
fine-tuning ↓ Held-out offline validation ↓ Closed-loop simulation/robot
evaluation ↓ Additional demonstrations or RL refinement

```mermaid
flowchart TD
    A["1. CAD Modeling<br/>Design the robot in Fusion360."]
    B["2. Simulation<br/>Validate design and train first policy."]
    C["3. Real World Fine Tuning<br/>Collect data and fine tune policy."]
    A --> B --> C
```

How Models Bridge the Hardware GapTo make transfer as easy as possible, these
models use specific tricks to abstract away hardware differences:Action Space
Normalization: Models rarely predict raw motor voltages or specific joint
angles. Instead, they output End-Effector Delta Poses ($\Delta x, \Delta y,
\Delta z, \Delta \text{roll}, \Delta \text{pitch}, \Delta \text{yaw},
\text{gripper status}$).Why this helps: "Move 2cm left and close the claw" is
universally understood, whether your robot has 6 joints, 7 joints, or linear
actuators.Inverted Kinematics (IK): The model tells your robot where the hand
should go in 3D space ($\Delta xyz$), and your local robot controller uses IK to
figure out what joint movements are required.Camera Normalization: Cameras are
typically resized and normalized to fixed resolutions (e.g., 224x224 RGB) so the
visual backend can process them regardless of the camera model.

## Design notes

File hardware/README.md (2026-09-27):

# Feetech STS3215 calibration and teleoperation

These utilities use LeRobot's Feetech support. Bus diagnostics, leader
calibration, and MuJoCo teleoperation never command servo positions. Physical
follower teleoperation does command positions and must be tested progressively.

## Control and calibrate the FMC4030 CNC

The guarded CNC utility communicates with the controller at
`192.168.0.30:8088` by default. Test TCP connectivity without transmitting a
controller command:

```bash
.venv/bin/python hardware/control_fmc4030.py check
```

After installing the project in editable mode, the equivalent command is
`.venv/bin/hepha-cnc check`.

Read the current X/Y/Z positions, speeds, limit inputs, axis states, and homing
state without causing motion:

```bash
.venv/bin/python hardware/control_fmc4030.py status
```

Before any automatic travel, manually activate every negative and positive
limit switch one at a time and run `status` after each activation. Confirm that
the correct axis and direction changes to `TRIGGERED`. Do not commission the
machine if this mapping is wrong.

Home all axes sequentially toward their negative switches:

```bash
.venv/bin/python hardware/control_fmc4030.py home \
  --axes x y z \
  --direction negative \
  --speed 10 \
  --acceleration 20 \
  --backoff 5
```

### Actively find and record min, mid, and max

The endpoint calibration deliberately matches the simple manual procedure that
works with this controller. For one selected axis it:

1. sends one bounded relative move toward MIN;
2. waits for the calculated move duration plus a settling margin;
3. opens a fresh connection, reads status once (with read-only retries), and
   verifies that the axis is stopped and its negative limit is active;
4. moves 5 mm away from the switch;
5. repeats the same process toward MAX and backs away again; and
6. saves both safe endpoints and their midpoint together.

There is no status polling while an axis is moving, and the old incremental and
parallel calibration commands have been removed. Calibrate one axis at a time:

```bash
.venv/bin/python hardware/control_fmc4030.py \
  --status-timeout 3 \
  calibrate-axis \
  --axis x \
  --status-read-timeout 120
```

Run the same command with `--axis y` and `--axis z` to calibrate those axes. The
defaults reproduce the tested motion: 600 mm maximum travel in each direction,
20 mm/s speed, 200 mm/s² acceleration/deceleration, a 5 mm backoff, and a 2
second settling margin. You can override them explicitly, for example:

```bash
.venv/bin/python hardware/control_fmc4030.py calibrate-axis \
  --axis y \
  --max-travel 600 \
  --speed 20 \
  --acceleration 200 \
  --deceleration 200 \
  --backoff 5 \
  --settle-seconds 2 \
  --status-read-timeout 120
```

Results are updated atomically in
`hardware/fmc4030_limit_calibration.json`. Previously calibrated axes are
preserved, and nothing from the current axis is saved unless both limit checks
succeed. If a command, wait, or status check is interrupted, the utility also
requests an immediate stop for the selected axis.

`--status-timeout` is one interruptible TCP receive window. During calibration,
`--status-read-timeout` is the total deadline for each endpoint status read.
The default permits as many 3-second receive windows as fit within 120 seconds;
it no longer fails after only five slow windows.

Calibrate X, Y, and Z sequentially with one confirmation using:

```bash
.venv/bin/python hardware/control_fmc4030.py \
  --status-timeout 10 \
  calibrate-all-axes \
  --status-read-timeout 300
```

The default order is X, Y, Z and can be changed with `--order`, for example
`--order z x y`. Each axis completes its MIN and MAX sequence before the next
axis starts. All six endpoints are written atomically only after all three axes
succeed, preventing a partial run from mixing calibration coordinate frames.

### Move to named positions A and B

`goto-position` reads `hardware/fmc4030_limit_calibration.json` and derives the
requested absolute position from its current safe MIN, MID, and MAX values:

- A = `(X mid, Y min, Z max)`
- B(drawer) = `(X mid - delta_1, Y min + 50 mm + delta_2, Z min)`

Move to A:

```bash
.venv/bin/python hardware/control_fmc4030.py goto-position --position A
```

Position B requires a drawer number:

```bash
.venv/bin/python hardware/control_fmc4030.py goto-position \
  --position B \
  --drawer 9
```

The original drawer `delta_1` is inverted before being applied to X. The
drawer-row `delta_2` remains active relative to the new Y base:

| Drawer | delta_1 | Applied X offset | delta_2 | Applied Y |
| -----: | ---: | ---: | ---: | --- |
| 1 | -50 mm | +50 mm | +50 mm | Y min + 100 mm |
| 2 | 0 mm | 0 mm | +50 mm | Y min + 100 mm |
| 3 | +50 mm | -50 mm | +50 mm | Y min + 100 mm |
| 4 | -50 mm | +50 mm | 0 mm | Y min + 50 mm |
| 5 | 0 mm | 0 mm | 0 mm | Y min + 50 mm |
| 6 | +50 mm | -50 mm | 0 mm | Y min + 50 mm |
| 7 | -50 mm | +50 mm | -50 mm | Y min |
| 8 | 0 mm | 0 mm | -50 mm | Y min |
| 9 | +50 mm | -50 mm | -50 mm | Y min |

The utility rejects a missing drawer for B, a drawer supplied for A, an incomplete
calibration, a controller-address mismatch, or any computed target outside a
safe calibrated interval before transmitting motion. It sends the absolute
axis commands back-to-back so they execute in parallel, then returns as soon as
the controller acknowledges them. Controller motion may continue after the
process exits. Named position commands also start immediately without an Enter
confirmation.

The slow initial status read is skipped by default. Add `--read-initial-status`
to verify that the axes are initially stopped, skip axes already at target, and
calculate a shorter wait from their current positions. This optional read does
not affect positioning mode: every movement packet remains absolute.
Add `--read-final-status` to perform the slow final stopped-state and position
verification. In that mode the utility waits using the largest calibrated axis
span before requesting status. Initial and final reads can be enabled
independently; both are skipped by default.

Defaults are 200 mm/s speed, 200 mm/s² acceleration, and 200 mm/s² deceleration.
Override them, the command transmission order, or status deadline when needed:

```bash
.venv/bin/python hardware/control_fmc4030.py \
  --status-timeout 3 \
  goto-position \
  --position B \
  --drawer 3 \
  --speed 10 \
  --acceleration 100 \
  --deceleration 100 \
  --order z x y \
  --status-read-timeout 300 \
  --read-initial-status \
  --read-final-status
```

After homing, move to any saved combination with `goto`:

```bash
.venv/bin/python hardware/control_fmc4030.py goto \
  --x min \
  --y mid \
  --z max
```

Axes move sequentially. The default order is Z, X, Y; change it for the
collision-safe order of the real machine with, for example,
`--order z y x`. The `goto` command accepts only `min`, `mid`, or `max` and
rejects a configuration created for a different controller address.

The raw homing endpoint does not acknowledge the transmitted command. After
sending it once, the utility monitors controller status until homing completes.
`--motion-timeout` is the maximum monitoring time (120 seconds per axis by
default); increase it for a long, slow axis, for example
`--motion-timeout 300`. The general `--timeout` option controls ordinary TCP
connections and motion-command acknowledgements. Status replies have a separate
3-second response window and make up to five read-only attempts; override it
globally with `--status-timeout` if this controller needs a longer window.

One persistent TCP connection is reused throughout each command workflow.
Before the first status request on a new connection, the client reads the
94-byte parameter block with `01 12`; this controller firmware otherwise
intermittently ignores a direct `01 03` request. The warm-up is read-only.
Status polling parses the documented 60-byte machine-status block immediately;
the unused 600-byte filename table is drained with a short bound and a delayed
table causes a clean reconnect instead of invalidating that status sample.
Read-only status transactions make exactly five total attempts before failing,
including connection establishment. Immediate single-axis stop is also retried
up to five times because repeating it is safe; the client briefly settles and
consumes an optional stop echo before polling again. Motion packets are never
retransmitted after sending: if their acknowledgement is lost, repeating a
relative move could duplicate the commanded travel.

If a status response is merely delayed, those receive attempts continue on the
same outstanding `01 03` request and TCP session. They do not repeatedly close
and reopen connections, which can strand this embedded single-client server on
an abandoned session. On process exit the socket uses an abortive close so the
firmware releases its single client immediately for the next CLI invocation.

Before motion, status may use all five short attempts. Once an axis is moving,
one missing status sample aborts the workflow and requests immediate stop; the
search never continues blindly until `--search-timeout`.

For a first packet-level physical test, clear the machine workspace, provide a
physical power cutoff, and request only a small, slow relative movement:

```bash
.venv/bin/python hardware/control_fmc4030.py move \
  --axis x \
  --position 1 \
  --mode relative \
  --speed 5 \
  --acceleration 10 \
  --deceleration 10
```

Every motion workflow shows its plan and pauses for Enter immediately before
the first command. A missing acknowledgement after transmission is reported as
an unknown machine state and is never retried automatically. Active limit
calibration uses the documented immediate single-axis stop packet; a physical
power cutoff is still required because software and Ethernet cannot provide an
independent emergency stop. No controller software-limit parameters are
changed, and MuJoCo limits are not treated as physical machine limits.

## Install Feetech support

The repository already uses `.venv`. Install the optional Feetech SDK once:

```bash
.venv/bin/python -m pip install "lerobot[feetech]==0.6.1"
```

The STS3215 bus must have the correct external supply connected. USB powers the
bus adapter, not the servos. Use the voltage specified on your servo model.

## Detect one bus, discover its IDs, and monitor positions

Connect and power one arm's bus, then run:

```bash
.venv/bin/python hardware/read_feetech_positions.py
```

The script:

1. finds likely USB serial adapters on macOS;
2. probes the Feetech baud rates and discovers responding servo IDs;
3. continuously refreshes a table with each servo's robot element, raw
   position, and position in degrees.

Press `Ctrl+C` to stop. Example output:

```text
Feetech STS3215 bus monitor
Port: /dev/cu.usbmodem101
Baud: 1,000,000   Servos: 12   Elapsed:     84.6 s

 ID  Robot element          Raw   Position
---  ------------------  ------  ---------
  1  shoulder right       831     73.04°
  2  shoulder left       3299    289.95°
```

For scrolling CSV output suitable for saving to a file, use:

```bash
.venv/bin/python hardware/read_feetech_positions.py --format csv
```

If both arm adapters are connected, select one explicitly:

```bash
.venv/bin/python hardware/read_feetech_positions.py \
  --port /dev/cu.usbmodem101
```

To verify the expected IDs and read at 20 Hz:

```bash
.venv/bin/python hardware/read_feetech_positions.py \
  --port /dev/cu.usbmodem101 \
  --ids 1 2 3 4 5 6 \
  --rate 20
```

To scan without starting the monitor:

```bash
.venv/bin/python hardware/scan_feetech_ids.py
```

Every servo on a bus must have a unique ID. Duplicate IDs cannot be reliably
distinguished because their replies collide on the shared wire.

## Read a USB camera

List camera indices that OpenCV can read:

```bash
.venv/bin/python hardware/read_usb_camera.py --list
```

Open the first detected camera in a live preview:

```bash
.venv/bin/python hardware/read_usb_camera.py
```

Select a particular camera index with `--index 0`. For a terminal-only test,
use `--no-display`; `--frames 100` optionally stops after 100 frames. On macOS,
camera access must be enabled for Terminal or Codex under System Settings,
Privacy & Security, Camera.

## Record physical leader-to-follower teleoperation

The physical recorder commands the calibrated follower from the leader while
recording the follower's measured joint positions, the exact absolute joint
commands sent to it, and RGB frames from the USB camera. Its LeRobot schema contains no
CNC action, CNC observation, drawer condition, or MuJoCo state.

Authenticate once before uploading:

```bash
.venv/bin/hf auth login
```

Then record and upload, replacing `YOUR_HF_USER` with your Hugging Face account:

```bash
.venv/bin/python -m hepha_lerobot.recording.physical_teleop \
  --repo-id YOUR_HF_USER/hepha_physical_teleop \
  --root datasets/hepha_physical_teleop \
  --leader-port /dev/cu.usbmodem58FA1019951 \
  --follower-port /dev/cu.usbmodem58FA1020401 \
  --camera-index 0 \
  --episodes 20 \
  --episode-seconds 60 \
  --push-to-hub
```

The camera preview is enabled by default. At the end of each attempt, choose
`SAVE`, `DISCARD`, `RETRY`, or `QUIT`. Only saved episodes are finalized and
uploaded. Use a new `--root` for another dataset; `--overwrite` intentionally
replaces an existing local recording.

## Run a trained ACT or PI0 policy on the physical follower

The physical rollout uses the same 12-joint order, calibrated radians, RGB
camera preprocessing, and saved LeRobot pre/postprocessors as physical dataset
recording. It never uses the leader or CNC. Authenticate with Hugging Face when
the model repository is private.

Always start torque-disabled:

```bash
.venv/bin/python -m hepha_lerobot.evaluation.physical_rollout \
  --policy-path tmeynier/hepha_act_physical \
  --follower-port /dev/cu.usbmodem58FA1020401 \
  --camera-index 0 \
  --device mps \
  --dry-run
```

The dry run reads the real follower and camera and displays predictions without
writing a goal position. Support the unpowered arms. Confirm that the camera is
correct, inference is responsive, the checkpoint reports 12 state/action
dimensions, and predicted targets are finite before enabling motion.

PI0 uses the same hardware safety path and the official saved LeRobot policy,
preprocessor, and postprocessor. Install its optional dependencies once:

```bash
uv pip install --python .venv/bin/python -e ".[pi0]"
```

The physical observation keeps the dataset key `observation.images.head_camera`.
The rename saved during PI0 training converts it to
`observation.images.base_0_rgb`, and the task text is passed to PI0's tokenizer.
Test a PI0 checkpoint torque-disabled first (a large PI0 checkpoint may be slow
or exceed the unified memory available on a Mac):

```bash
.venv/bin/python -m hepha_lerobot.evaluation.physical_rollout \
  --policy-path tmeynier/hepha_pi0_physical_v2 \
  --follower-port /dev/cu.usbmodem58FA1020401 \
  --camera-index 0 \
  --device mps \
  --task "Put the white cube in the bowl" \
  --n-action-steps 10 \
  --fps 5 \
  --watchdog-seconds 120 \
  --dry-run
```

Do not pass `--temporal-ensemble-coeff` to PI0. PI0 uses its own flow-matching
inference and action queue; temporal ensembling is ACT-only.

### Run policy inference on a remote GPU

LeRobot 0.6.1 includes an asynchronous gRPC policy server. Hepha can use that
server while keeping the camera, servo bus, safety limiter, UI, and torque
shutdown on the Mac. The remote server returns postprocessed chunks of 12
absolute joint targets; Hepha overlaps the next request with execution of the
current chunk.

The LeRobot transport is unauthenticated and serializes Python objects. Never
publish its port to the internet. Bind it to loopback on RunPod and carry it
through an SSH tunnel. The private SSH key remains in `~/.ssh` and is handled by
OpenSSH; it is deliberately not passed to Python or stored in this repository.

On RunPod, install the same repository and LeRobot version used on the Mac:

```bash
cd /workspace/hepha
source .venv/bin/activate
uv pip install --python .venv/bin/python -e ".[pi0,remote]"
```

Authenticate with Hugging Face on RunPod if the checkpoint is private, then
start the server. Keep `--host=127.0.0.1`; do not expose port 8080 as a RunPod
public TCP port:

```bash
cd /workspace/hepha
source .venv/bin/activate
python -m lerobot.async_inference.policy_server \
  --host=127.0.0.1 \
  --port=8080 \
  --fps=5 \
  --inference_latency=0 \
  --obs_queue_timeout=10
```

In a separate Mac terminal, use the SSH hostname and port shown by RunPod's
**Connect** panel. This terminal remains occupied while the tunnel is active:

```bash
ssh -i /Users/YOUR_USER/.ssh/runpod_ed25519 \
  -p RUNPOD_SSH_PORT \
  -N \
  -L 8080:127.0.0.1:8080 \
  -o ExitOnForwardFailure=yes \
  -o ServerAliveInterval=30 \
  root@RUNPOD_SSH_HOST
```

Install only the lightweight remote client dependencies on the Mac; PI0 itself
does not need to load there:

```bash
.venv/bin/python -m pip install -e ".[remote]"
```

Run the first test torque-disabled. In remote mode, `--policy-path` is resolved
by RunPod, not by the Mac. It can be a Hugging Face repository ID or an absolute
checkpoint directory already downloaded on RunPod:

```bash
.venv/bin/python -m hepha_lerobot.evaluation.physical_rollout \
  --policy-path tmeynier/hepha_pi0_physical_v2 \
  --remote-server 127.0.0.1:8080 \
  --remote-policy-type pi0 \
  --remote-policy-device cuda \
  --follower-port /dev/cu.usbmodem58FA1020401 \
  --camera-index 0 \
  --task "Put the white cube in the bowl" \
  --n-action-steps 10 \
  --fps 5 \
  --remote-load-timeout 300 \
  --remote-request-timeout 10 \
  --watchdog-seconds 15 \
  --duration-seconds 60 \
  --dry-run
```

Once the dry run is responsive and the predictions look safe, repeat without
`--dry-run`. A lost tunnel, failed remote request, invalid action, or watchdog
expiry raises an error and exits the follower context, which disables torque.
Use the exact same LeRobot version on both machines because the protocol sends
version-specific Python data classes.

For the first powered test, clear the full workspace and keep immediate power
removal within reach:

```bash
.venv/bin/python -m hepha_lerobot.evaluation.physical_rollout \
  --policy-path tmeynier/hepha_act_physical \
  --follower-port /dev/cu.usbmodem58FA1020401 \
  --camera-index 0 \
  --device mps \
  --max-velocity-deg 10 \
  --acceleration 30 \
  --torque-limit 300
```

SPACE in the camera window is the final torque-enable confirmation. Q, Escape,
Ctrl+C, a camera/bus exception, a non-finite action, or a control-cycle watchdog
failure stops the rollout; follower cleanup disables torque. Commands are
clamped to calibrated joint ranges and rate-limited. The physical scene and
starting pose must resemble the demonstrations, and the CNC must remain in the
same fixed position represented in the arm-only dataset.

## Calibrate a complete leader or follower arm

Leader and follower calibration now use the same simultaneous range-sweep
procedure. Calibration always covers all 12 servos on the selected bus; there
is no per-axis mode and no separate MIN, HOME, or MAX prompt.

Support the complete arm before starting because torque is disabled on all 12
servos together. Start leader calibration with:

```bash
.venv/bin/python hardware/calibrate_feetech_positions.py \
  --port /dev/cu.usbmodem58FA1019951
```

Start follower calibration with:

```bash
.venv/bin/python hardware/calibrate_feetech_follower.py \
  --port /dev/cu.usbmodem58FA1020401
```

The unified form is equivalent:

```bash
.venv/bin/python -m hardware.calibrate_feetech \
  --role leader \
  --port /dev/cu.usbmodem58FA1019951
```

Recording begins immediately after the bus is connected and torque is disabled.
Move every joint through its complete physical range, in any order and as many
times as useful. The command continuously reads all 12 encoders together. Press
Enter once every joint has reached both endpoints.

For each servo, the software continuously unwraps the cyclic 0–4095 encoder,
stores the smallest and largest observed positions, and defines HOME as their
exact midpoint. The joint-space HOME is likewise the midpoint between that
joint's configured MuJoCo minimum and maximum. Encoder direction cannot be
deduced from an unordered range sweep, so its sign is part of the canonical ID
mapping in `hardware/axes.py`; leader and follower use the same signs.

The complete calibration is validated and then replaces the selected role's
JSON atomically:

- leader: `hardware/feetech_calibration.json`
- follower: `hardware/feetech_follower_calibration.json`

If any servo moved fewer than 100 encoder steps, or if an observed interval
spans a complete encoder revolution, nothing is saved. Ctrl+C also cancels the
whole run without changing the existing JSON. Supplying `--port` skips the slow
port and baud-rate scan; all IDs 1–12 are pinged once on that connection.

Follower capture is identical to leader capture. After recording, the follower
command automatically centers every measured midpoint at raw 2048, selects
position-control mode, and writes non-wrapping hardware limits. It never sends
a goal position; all calibration movement remains manual.

## Teleoperate a physical follower

Always begin with one joint and `--dry-run`. The dry run disables torque on the
selected leader and follower axes, compares their calibrated joint angles, and
prints live targets without writing follower goals:

```bash
.venv/bin/hepha-follow \
  --leader-port /dev/cu.LEADER_PORT \
  --follower-port /dev/cu.FOLLOWER_PORT \
  --joints shoulder_l \
  --dry-run
```

When the readings and directions are correct, remove `--dry-run`:

```bash
.venv/bin/hepha-follow \
  --leader-port /dev/cu.LEADER_PORT \
  --follower-port /dev/cu.FOLLOWER_PORT \
  --joints shoulder_l
```

The leader and follower do not need to start aligned. The program seeds every
follower goal from that servo's present position before enabling torque, then
automatically approaches the current leader pose at 10 degrees per second by
default. Hold the leader still during this phase. Normal teleoperation begins
when every selected joint is within 5 degrees. Use `--startup-velocity-deg`,
`--startup-tolerance-deg`, and `--startup-timeout-seconds` to adjust this
transition. During operation it clamps joint limits, limits target motion to 30
degrees per second by default, and disables follower torque on exit, timeout,
or any communication error.

After testing axes individually, operate the complete left arm with:

```bash
.venv/bin/hepha-follow \
  --leader-port /dev/cu.LEADER_PORT \
  --follower-port /dev/cu.FOLLOWER_PORT \
  --joints shoulder_l forearm_l arm_l wrist_l hand_l finger_l
```

Use a physical emergency power cutoff and keep the follower workspace clear.
The leader and follower serial ports must be different.

## Run one physical teleoperation episode

The episode command continuously mirrors the physical leader onto the physical
follower while coordinating this CNC sequence:

1. command position A automatically;
2. wait for SPACE, then command position B for a randomly selected drawer;
3. wait for SPACE, then command position A again; and
4. wait for SPACE once more to finish the episode.

The selected drawer is printed prominently at startup. CNC packet transmission
runs in a background worker, so Feetech reading and follower commands continue
at the requested control frequency while the CNC is being commanded and moving.
SPACE is accepted only after a conservative CNC movement delay; slow controller
status reads are not used. Ctrl+C or an error disables follower torque and sends
an immediate stop request to all CNC axes.

```bash
.venv/bin/python hardware/teleoperate_episode.py \
  --leader-port /dev/cu.usbmodem58FA1019951 \
  --follower-port /dev/cu.usbmodem58FA1020401
```

After an editable install, the equivalent entry point is:

```bash
.venv/bin/hepha-teleop-episode \
  --leader-port /dev/cu.usbmodem58FA1019951 \
  --follower-port /dev/cu.usbmodem58FA1020401
```

Use `--drawer 1` through `--drawer 9` to test a fixed drawer, or `--seed`
to reproduce a randomized selection. All joints calibrated on both arms are
teleoperated by default; `--joints` can select a subset. This test version does
not write a dataset. Each control cycle is already represented as an
`EpisodeFrame` and sent through the `EpisodeSink` interface in
`hardware/teleop_episode.py`; a later LeRobot sink can store those frames and
CNC phase transitions without changing the hardware-control loop.

## Test calibrated axes in MuJoCo

After calibrating the left shoulder (servo ID 2), run:

```bash
.venv/bin/python hardware/teleoperate_mujoco_joint.py --id 2
```

The utility disables torque only on the selected physical servo, reads its
position, maps it piecewise through the captured minimum/home/maximum points,
and drives only the corresponding MuJoCo arm actuator. At startup, the MuJoCo
CNC axes are placed at `cnc_x=0`, `cnc_y=0`, and the `head_z` minimum
(`-0.1 m`). It never sends a position command to the physical servo. Close the
MuJoCo viewer or press `Ctrl+C` to stop.

To teleoperate several calibrated axes simultaneously, list their servo IDs:

```bash
.venv/bin/python hardware/teleoperate_mujoco_joint.py --ids 2 4
```

The utility reads all selected servos together and disables torque only for
those axes. Support every selected physical axis before confirming.

Encoder smoothing is enabled by default. To see unsmoothed values:

```bash
.venv/bin/python hardware/teleoperate_mujoco_joint.py --id 2 --smoothing 1
```

## Record MuJoCo episodes from the physical leader

The interactive recorder uses the calibrated, torque-disabled physical servos
as a leader while storing MuJoCo camera observations, simulated joint state,
and the exact actions applied to the simulator in LeRobot format. It runs in a
single process and asks whether to save, discard, retry, or quit after every
attempt.

```bash
.venv/bin/python -m hepha_lerobot.recording.teleop \
  --ids 1 2 3 4 5 6 7 8 9 10 11 12 \
  --repo-id hepha/mujoco_feetech_teleop \
  --root datasets/hepha_mujoco_feetech_teleop \
  --episodes 20 \
  --episode-seconds 60 \
  --fps 30
```

After reinstalling the editable project, the equivalent console command is
`.venv/bin/hepha-teleop-record`. The recorder fixes `cnc_x=0`, `cnc_y=0`, and
`head_z` at its minimum. It omits automatic IK task-phase labels; drawer and
task conditioning remain present.

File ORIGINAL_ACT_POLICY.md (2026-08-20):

# Original ACT Policy

## Implementation

- Standard LeRobot ACT policy.
- ResNet-18 visual backbone.
- ACT transformer with CVAE training.
- Action chunk: 100 steps.
- Closed-loop evaluation used one action per frame.
- Temporal-ensemble coefficient: `0.01`.

## Input

- Head-camera RGB image: `3 × 256 × 256`.
- Robot joint state: 15 joint positions.
- Requested drawer: 9-value one-hot vector.

## Output

- Absolute joint-position targets.
- Shape: `100 × 15` per predicted action chunk.

## Dataset and model

- Training dataset: `tmeynier/hepha_mujoco_ik` on Hugging Face.
- RunPod dataset path: `/workspace/datasets/hepha_mujoco_ik`.
- Local dataset is not currently stored in this repository.
- Model: `tmeynier/hepha_act_200` on Hugging Face.
- Local model: `models/hepha_act_200`.

## Closed-loop results

- Evaluation: 100 episodes of 100 seconds.
- Seeds: `10000–10099`.
- Domain randomization: disabled.
- Drawer opened at least 40 mm: **100%**.
- Cube stably grasped: **32%**.
- Cube entered the selected drawer: **11%**.
- Drawer closed to at most 5 mm after insertion: **11%**.
- Final cube-inside-and-drawer-closed success: **2%**.
- Successful final-state seeds: `10024`, `10029`.
- Task reached temporarily: **11%**.
- Task retained until the end: **2%**.

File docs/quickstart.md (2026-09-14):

# Hepha simulation-to-policy quickstart

Hepha is an external LeRobot robot plugin with pluggable simulation backends.
The installed official LeRobot package owns dataset serialization, every policy,
training, preprocessing, checkpoints, and policy rollout. Hepha supplies only the
simulation adapters, demonstration controllers, and thin workflow launchers.

## Install

Python 3.12 is required by LeRobot 0.6.1.

```bash
python3.12 -m venv .venv
.venv/bin/python -m pip install --upgrade pip
.venv/bin/python -m pip install -e '.[dev]'
```

On macOS, MuJoCo's native viewer needs the `mjpython` launcher. The `hepha-view`
command switches to it automatically when it is available.

## Discover installed functionality

```bash
.venv/bin/hepha-view --list-backends
.venv/bin/hepha-record --backend mujoco --list-controllers
.venv/bin/hepha-policies
```

The policy list is obtained from LeRobot's live `PreTrainedConfig` registry, so it
tracks the installed LeRobot version and any installed `lerobot_policy_*` plugins.

## 1. View and control the robot

```bash
.venv/bin/hepha-view --backend mujoco
```

Use MuJoCo's native **Control** panel to move every actuator across its configured
control interval. Hepha does not override the panel's actuator targets.

Collision geometry, the head-camera axes, and the live cube-center coordinate
frame are hidden by default. Enable them with either boolean form:

```bash
.venv/bin/hepha-view --backend mujoco --debug
.venv/bin/hepha-view --backend mujoco --debug true
```

The cube frame remains attached to the cube as it moves. Other task-specific IK
frames appear when their targets are available.

## 2. Record an IK-generated LeRobot dataset

```bash
.venv/bin/hepha-record \
  --backend mujoco \
  --controller ik \
  --repo-id hepha/simulation_ik \
  --root datasets/hepha_simulation_ik \
  --episodes 20 \
  --episode-seconds 360 \
  --viewer true \
  --debug true \
  --cube-grasp-lock true \
  --cube-drop-assist true
```

Each frame contains `observation.state`, `observation.images.head_camera`,
`observation.environment_state`, `action`, and a task string in LeRobotDataset v3
format. The environment state stores the requested-drawer one-hot vector, a two-way
`workspace_A`/`workspace_B` one-hot vector, and the five-way task phase. Numeric CNC
joint positions remain in `observation.state`; the categorical workspace complements
rather than replaces those measurements. Workspace-aware datasets store only the 12
arm and finger targets in `action`; CNC targets are deterministic coordinator outputs.

The demonstrations follow the physical sequence `A -> B -> A -> B -> A`: start by
the storage bin, open the selected drawer, return to pick the cube, return to place
the cube and close the drawer, then finish at the storage bin. The workspace
coordinator alone commands the three CNC joints. Position-and-orientation IK controls
only the arm joints, so it cannot silently turn a discrete workspace into a
continuous gantry trajectory. Both A and B use a CNC-Y target 2 cm above the
middle-drawer center reference. Before every A/B transfer, both arms enter a
symmetric shoulder-raised transit pose and all four fingertips must clear the 9 cm storage-bin walls by at
least 1 cm; otherwise the episode aborts before CNC motion. The hand closest to the requested
drawer opens it first, then the hand closest to the cube grasps and lifts the cube.
If those are different hands, the cube is passed physically to the drawer-side
hand before insertion. Center drawers 2, 5, and 8 are reachable by either arm, so
the cube-holding arm places the cube directly and no handoff is scheduled. The
episode starts from the user-selected mirrored working
pose. A normalized joint-space penalty (weight 300) keeps each IK result near that
fixed posture, a smaller continuity penalty (weight 30) discourages sudden IK-branch
changes, and every optimized arm joint is constrained to within 75 degrees of its
nominal value. Cartesian position and orientation remain the primary objectives.
Drawer-opening targets rotate the finger gap by -90 degrees on the left or
+90 degrees on the right so it is perpendicular to the horizontal handle. Cube
pickup uses a stronger orientation weight of 50 to keep the fingers approximately
parallel to the floor. IK waypoints are connected by smooth
joint-space and coordinated workspace motions. Cube grasping uses a 32 mm finger
gap, a short settling hold, and moderate compliant cube/fingertip contacts to
approximate a foam cube between plastic fingers. By default, handoff, transport,
and release remain physical and use no artificial grasp constraint. The optional
`--cube-grasp-lock true` mode captures the live hand-to-cube transform after a
successful close approach, holds that transform during transport, transfers it to
the receiver only after handoff contact is verified, and disables it before the
drawer drop. It therefore abstracts retention and simulated slipping without
turning a missed approach into a successful grasp. During handoff, the receiver
uses the cube-side pair perpendicular to the pair indicated by the donor hand's red
axis. It keeps its fingers fully open through both approach IKs and closes only after
reaching the cube center. Immediately before dropping the cube into the drawer,
cube/gripper friction is set to zero so the cube releases cleanly; normal collision
remains enabled, and grasp friction is restored on episode reset. The drawer-drop
assist is enabled by default: during the short release-settling phase it constrains
the cube center to the drawer's geometrically safe horizontal interior, removes
lateral and angular velocity, maintains a gentle descent until the cube approaches
the drawer floor, and then cancels upward rebound while leaving gravity and contact
to finish the landing. Pass `--cube-drop-assist false` for fully physical drop
dynamics. Failed or timed-out attempts are discarded.
Pass `--early-failures false` to turn task-quality aborts into warnings and watch
the complete sequence during debugging. The CNC fingertip-clearance stop, attempt
timeout, and final success validation remain active, so invalid episodes are never
silently saved.
`--episode-seconds` is an attempt timeout rather than a fixed episode length. Video
storage is enabled by default; add `--no-video` for a fast PNG-based debug run. By
default the recorder makes up to three attempts per requested successful episode;
use `--max-attempts` to change that limit. `--viewer` and `--viewer true` both
open MuJoCo's native viewer so the physical demonstration can be watched while
it is recorded; use `--viewer false` for headless recording. With `--debug true`,
the viewer also shows collision geometry, the head-camera axes, and the four IK
target frames. Each IK directly uses its displayed frame for both position and
orientation. The drawer-opening and drawer-closing frames overlap at the selected
handle center and follow the handle while the drawer moves. The cube-grasp and
cube-placement frames remain fixed for the episode.
The cube-center frame remains visible in the native viewer throughout a debug
episode. Debug geometry is never included in the recorded camera observation.

Evaluate the IK controller without recording a dataset:

```bash
.venv/bin/python -m hepha_lerobot.evaluation.ik_sweep \
  --episodes 10 \
  --episode-seconds 360 \
  --viewer true \
  --debug true \
  --early-failures false \
  --cube-grasp-lock true \
  --cube-drop-assist true
```

This runs exactly ten attempts and never retries merely to reach a requested
number of successes. Task-quality early failures become warnings; a failed
attempt is reported and the next seed starts automatically. The summary gives
cumulative rates for opening the drawer, grasping the cube, completing a
physical handoff when required, putting the cube in the selected drawer, and
closing it after insertion. Final closed-loop success requires the cube to
remain inside the selected drawer while that drawer is closed.

Inspect an episode with LeRobot's own visualizer:

```bash
.venv/bin/lerobot-dataset-viz \
  --repo-id hepha/simulation_ik \
  --root datasets/hepha_simulation_ik \
  --mode local \
  --episode-index 0
```

## 3. Train any LeRobot policy

Apple Silicon:

```bash
.venv/bin/hepha-train \
  --policy-type act \
  --repo-id hepha/simulation_ik \
  --root datasets/hepha_simulation_ik \
  --output-dir outputs/act \
  --device mps \
  --steps 100000
```

Use `--policy-type diffusion`, `smolvla`, or any value printed by
`hepha-policies`. Arguments after `--` are passed unchanged to `lerobot-train`,
which keeps policy-specific configuration available without adding policy logic
to Hepha:

```bash
.venv/bin/hepha-train \
  --policy-type diffusion \
  --repo-id hepha/simulation_ik \
  --root datasets/hepha_simulation_ik \
  -- --policy.n_action_steps=8
```

No model, normalizer, optimizer, checkpoint, or dataloader is reimplemented.
`--device auto` uses LeRobot's own device selection; add `--num-workers 0` for a
small smoke test. Policy-specific extras or pretrained models may still be
required by LeRobot.

## 4. Evaluate the policy in MuJoCo

```bash
.venv/bin/hepha-evaluate \
  outputs/act/checkpoints/last/pretrained_model \
  --backend mujoco \
  --device mps \
  --duration 30
```

This delegates policy execution to LeRobot's `lerobot-rollout` base strategy and
loads `--robot.type=hepha_simulation` through LeRobot's third-party plugin
discovery. The `--backend` value is independent of the trained policy.
Add `--headless` on a server.

The equivalent direct command is:

```bash
.venv/bin/lerobot-rollout \
  --strategy.type=base \
  --policy.path=outputs/act/checkpoints/last/pretrained_model \
  --robot.type=hepha_simulation \
  --robot.backend=mujoco \
  --robot.viewer=true \
  --duration=30
```

## 5. Collect DAgger corrections

First watch policy rollouts. Press Space at a state where a human correction
should begin. The current MuJoCo integration state and task metadata are saved,
and that rollout stops. Press N to skip a good episode without saving it, or Q
to finish. Closing the viewer also ends the command.

```bash
.venv/bin/hepha-dagger-mark models/hepha_act_phase_200 \
  --output-dir dagger/hepha_act_phase_200 \
  --episodes 20 \
  --episode-seconds 100 \
  --seed-start 20000 \
  --device mps \
  --n-action-steps 1 \
  --temporal-ensemble-coeff 0.01 \
  --domain-randomization-scale 0
```

Then restore each saved state. Use MuJoCo's native Control panel to command the
actuator targets, press 1–5 when the semantic phase changes, and press Space
when the short human correction is complete.
The joint targets are sampled at 30 Hz and Savitzky-Golay smoothed without
changing the frame count. Hepha then restores the marked state and records a
physics-consistent replay of the smoothed correction. A correction is discarded
if Space is not pressed.

```bash
.venv/bin/hepha-dagger-correct dagger/hepha_act_phase_200 \
  --repo-id tmeynier/hepha_dagger_corrections \
  --root datasets/hepha_dagger_corrections \
  --dataset-schema phase \
  --max-seconds 30 \
  --push-to-hub \
  --overwrite
```

During correction collection, Space saves, N discards and advances, R discards
the current attempt and restores the same marked state for another try, and Q
finishes gracefully. Every accepted correction is finalized first as an
independent dataset shard. If the command is interrupted, run the same command
again with `--resume` instead of `--overwrite`; already completed marked states
are skipped and the final dataset is rebuilt from all durable shards.

Use `--dataset-schema drawer` instead when extending an original ACT dataset
that has the drawer one-hot condition but no task-phase input or target. Finally,
merge corrections through LeRobot's native dataset aggregation and optionally
publish the result:

```bash
.venv/bin/hepha-dagger-merge \
  --base-repo-id tmeynier/hepha_mujoco_ik_phase_200 \
  --base-root datasets/hepha_mujoco_ik_phase_200 \
  --correction-repo-id tmeynier/hepha_dagger_corrections \
  --correction-root datasets/hepha_dagger_corrections \
  --repo-id tmeynier/hepha_mujoco_ik_phase_200_dagger \
  --root datasets/hepha_mujoco_ik_phase_200_dagger \
  --push-to-hub \
  --overwrite
```

## Project boundaries and extension points

```text
lerobot/                    Dataset, policy, recording, training, and rollout integration
lerobot/hepha_simulation.py Discoverable backend-neutral LeRobot Robot adapter
simulation/                 Backend contract, registry, and generic viewer
simulation/backends/mujoco MuJoCo implementation, MJCF, meshes, and IK
scripts/                    Generic convenience wrappers only
cad/                        Source CAD (intentionally untouched)
```

An Isaac Sim implementation subclasses `SimulationBackend` and can be exposed as
an entry point in the `hepha.simulation_backends` group. A controller can be
added through `hepha.demonstration_controllers` using the name
`isaac_sim.<controller>`. Recording, training, and evaluation then need only
`--backend isaac_sim`; their policy and dataset code does not change.

The plugin follows LeRobot's official
[custom hardware conventions](https://github.com/huggingface/lerobot/blob/main/docs/source/integrate_hardware.mdx).
ACT usage follows the official
[ACT guide](https://github.com/huggingface/lerobot/blob/main/docs/source/act.mdx),
and deployment uses the official
[rollout interface](https://github.com/huggingface/lerobot/blob/main/docs/source/inference.mdx).

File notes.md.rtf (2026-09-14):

- robot calibration
- new simulation setup for IK: start, reach drawer pos, reach cube pos, reach drawer pos, start
- drawer wood build finished

- KV caching is important
- not loose information from the VLM by trying
- the lightweight Action Head is optimized to master physical dynamics.
- being fast (also for failure detection) is a major challenge
- failures in dataset are as important as successes
- failure detection = prevent hallucination
- The first H′ (H′ ≤ H) actions in At are executed, and then the VLA replans a new action sequence At+H′ at time t + H′
- System 2 enables to make the architecture non markovian

Feature-wise Linear Modulation

Use Coin-Flip Network (CFN) from VLAConf
Use functional conformal prediction in System 2 as in SAFE

Standard DAgger addresses covariate shift in behavior cloning.

It tries to teach the policy to behave correctly from the distribution of states its policy actually visits.
Instead, RaC = pull back
That is especially useful for contact-rich manipulation, where continuing from an error state may be harder than backing out and trying again.

VLAConf = WHEN am I going wrong?
RaC = WHAT behavior should I learn to recover?
\boxed{\text{RaC = WHAT behavior should I learn to recover?}}

RaC relies on humans to recognize imminent failure and decide how far to rewind during data collection. Your idea could potentially replace parts of that with a learned VLA confidence/value model: automatically detect the confidence collapse, identify the last high-confidence region, and let System 2 command a learned retry. That combination is more specific than simply applying DAgger.

Long multi-step reasoning — maintaining a coherent computation/planning process over many steps.
Trial and error — exploring an approach and changing it when it doesn't work.
Backtracking — returning to an earlier decision rather than blindly continuing.
Self-correction / verification — checking intermediate or final results and revising them.
Planning and decomposition — breaking a difficult problem into manageable subproblems.
Long-context problem solving — keeping relevant intermediate state across a much longer trajectory.
Tool/code use, in some training setups — writing code, observing results, debugging, or otherwise interacting with an environment.

It's analogous to test-time scaling in reasoning models:
LLM: more reasoning/attempts→better answer
while RaC gets:
Robot: more recovery/retry opportunities→higher task success.
Crucially, the model weights don't change:
RaC treats recovery as yet another “skill” to learn from human demonstrations

FLARE's central insight is that there are actually two fundamentally different kinds of failure, requiring two different solutions:
Retry for recoverable errors +Reset for catastrophic errors

Conclusion:

- First do a normal pipeline with ACT

vider la corbeille + one full correct sequence + ask how to resell on amazon and galaxus +

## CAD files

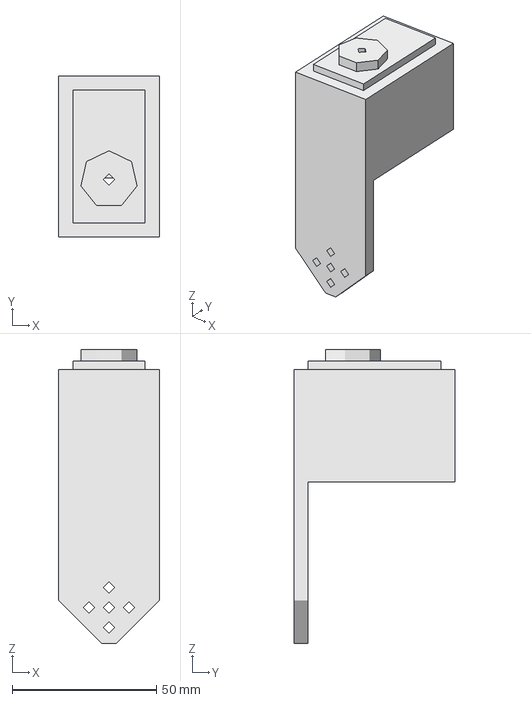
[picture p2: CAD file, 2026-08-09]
cad/assembly/left_wrist.FCStd
35.0 x 56.0 x 102.0 mm

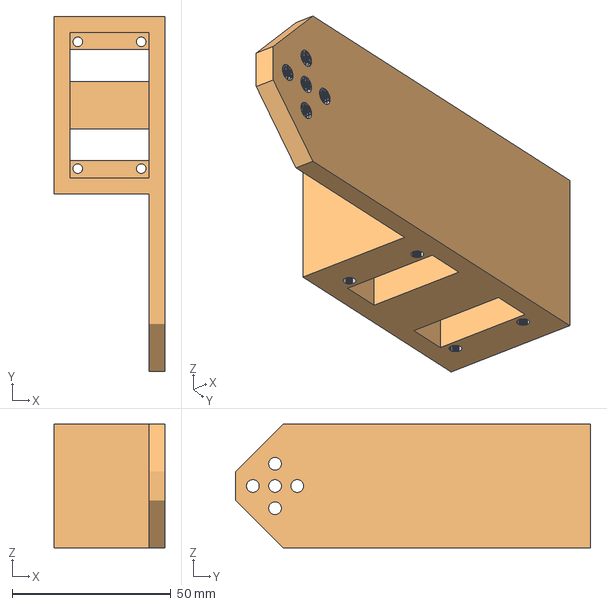
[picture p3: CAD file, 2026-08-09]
cad/parts/arms/arm/arm_left.FCStd
35.0 x 112.0 x 39.0 mm
Body (Meshed)

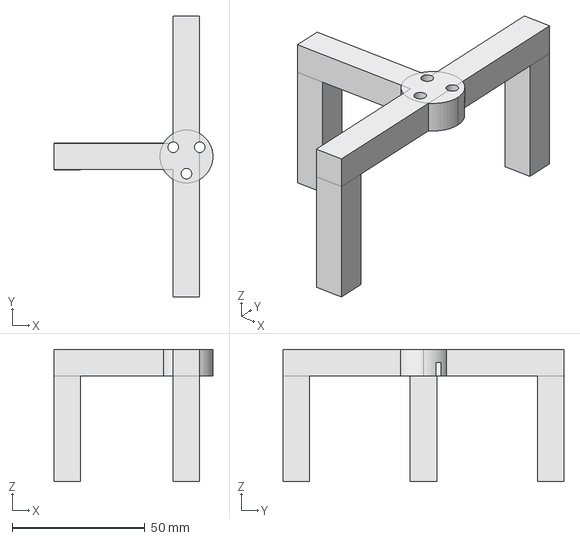
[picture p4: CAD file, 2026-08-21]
cad/parts/arms/eyes/top_cnc_z_fixator.FCStd
60.0 x 106.0 x 50.0 mm

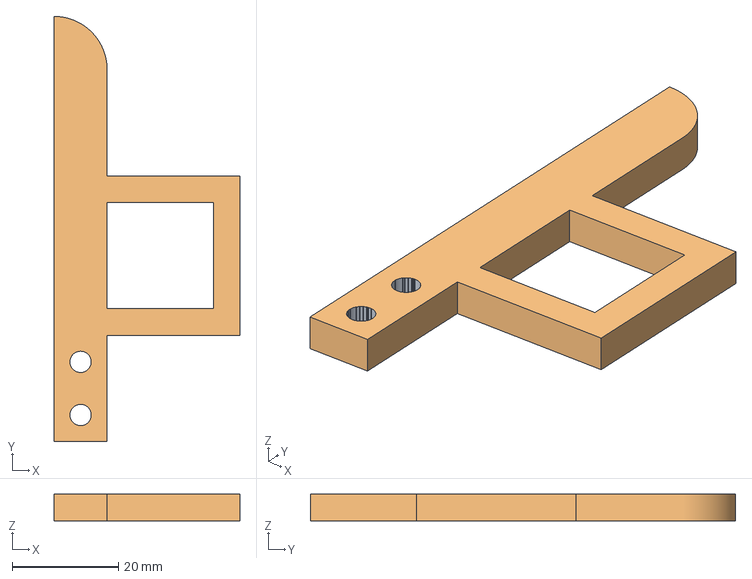
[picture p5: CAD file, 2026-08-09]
cad/parts/arms/fingers/finger_1_leader.FCStd
35.0 x 80.0 x 5.00 mm
Body (Meshed)

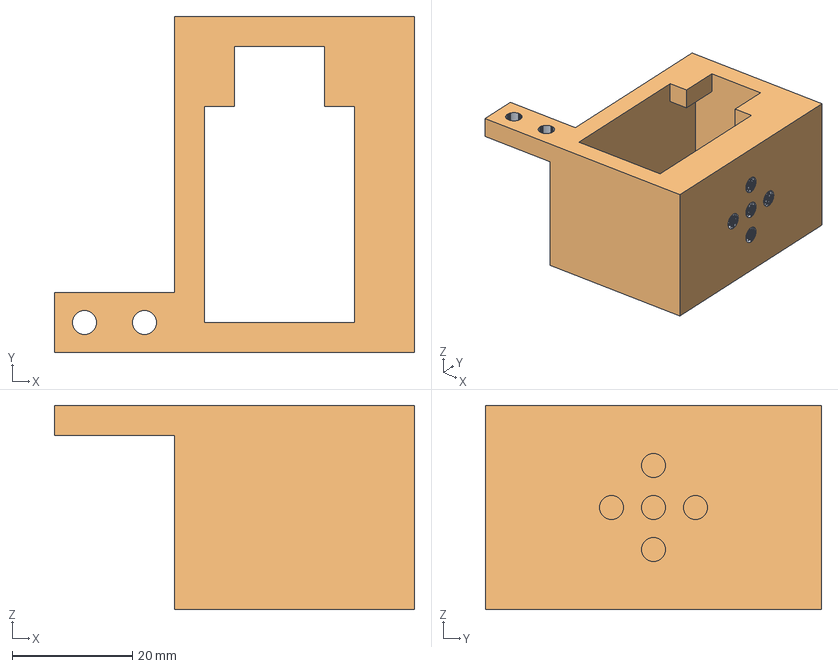
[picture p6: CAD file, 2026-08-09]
cad/parts/arms/hand/hand_left.FCStd
60.0 x 56.0 x 34.0 mm
Body (Meshed)

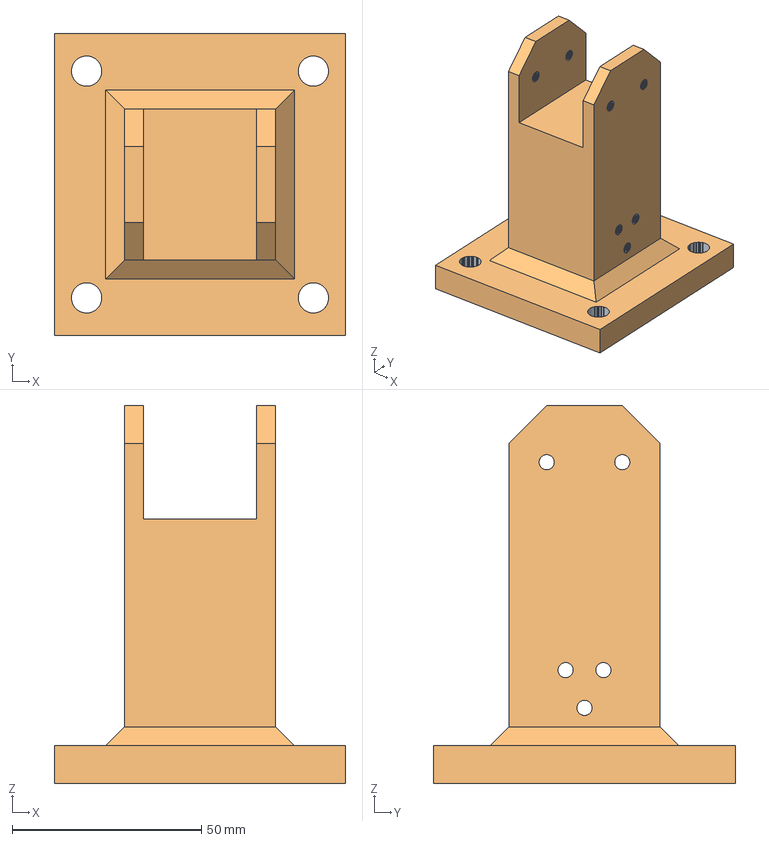
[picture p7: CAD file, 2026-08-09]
cad/parts/arms/head/head_part_0.FCStd
77.0 x 80.0 x 100.0 mm
Body (Meshed)

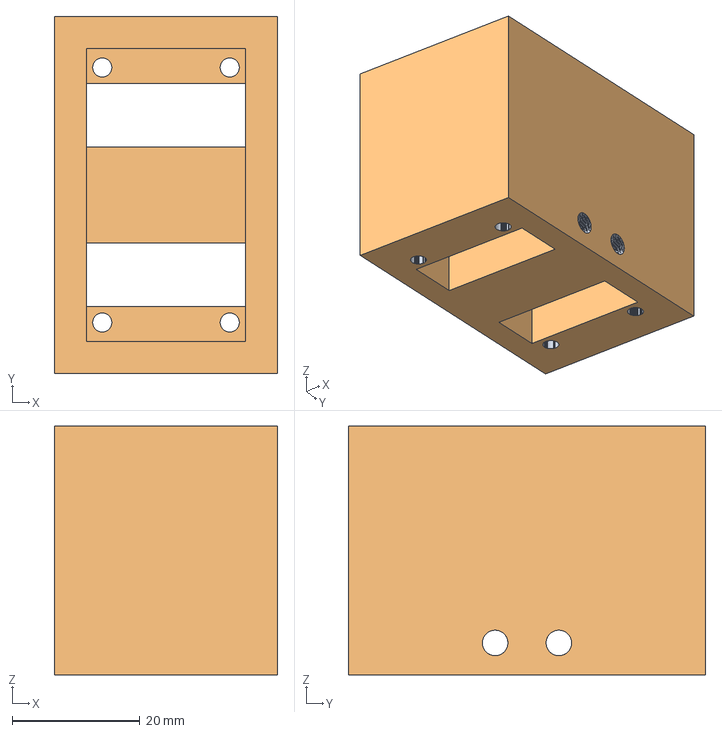
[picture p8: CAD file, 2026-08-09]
cad/parts/arms/servo_motor_attach.FCStd
35.0 x 56.0 x 39.0 mm
Body (Meshed)

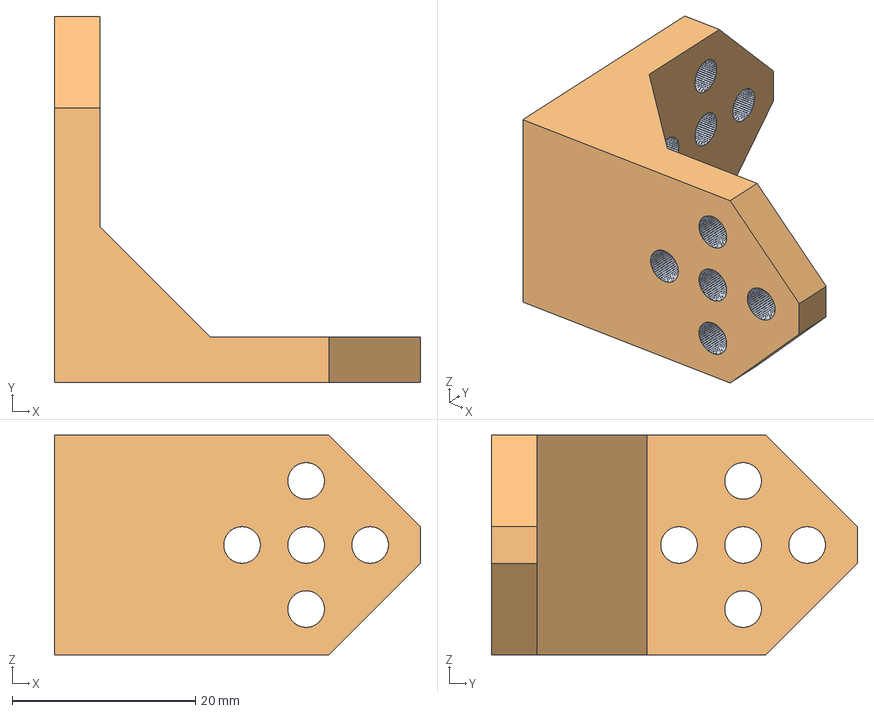
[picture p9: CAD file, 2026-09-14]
cad/parts/arms/shoulder/shoulder.FCStd
40.0 x 40.0 x 24.0 mm
Body (Meshed)

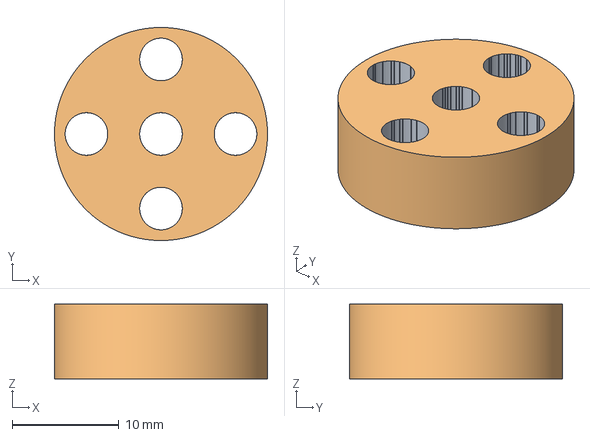
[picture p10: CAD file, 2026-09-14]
cad/parts/arms/wrist/wrist_axis.FCStd
20.0 x 20.0 x 7.00 mm
Body (Meshed)

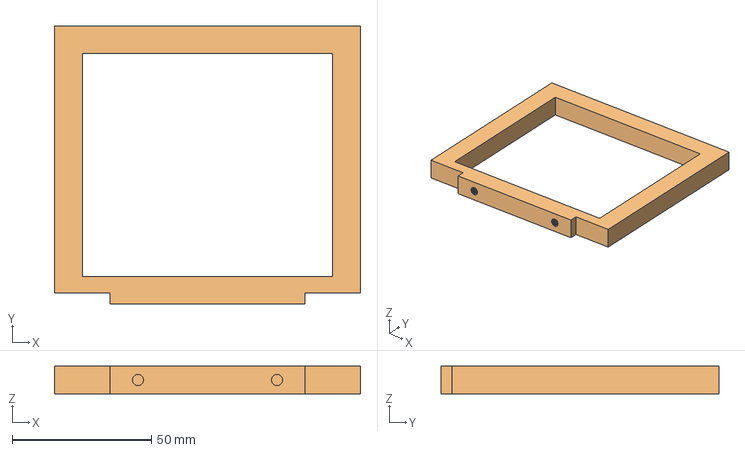
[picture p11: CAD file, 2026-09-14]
cad/parts/drawers/rack_structure_holder.FCStd
110.0 x 100.0 x 10.0 mm
Body (Meshed)

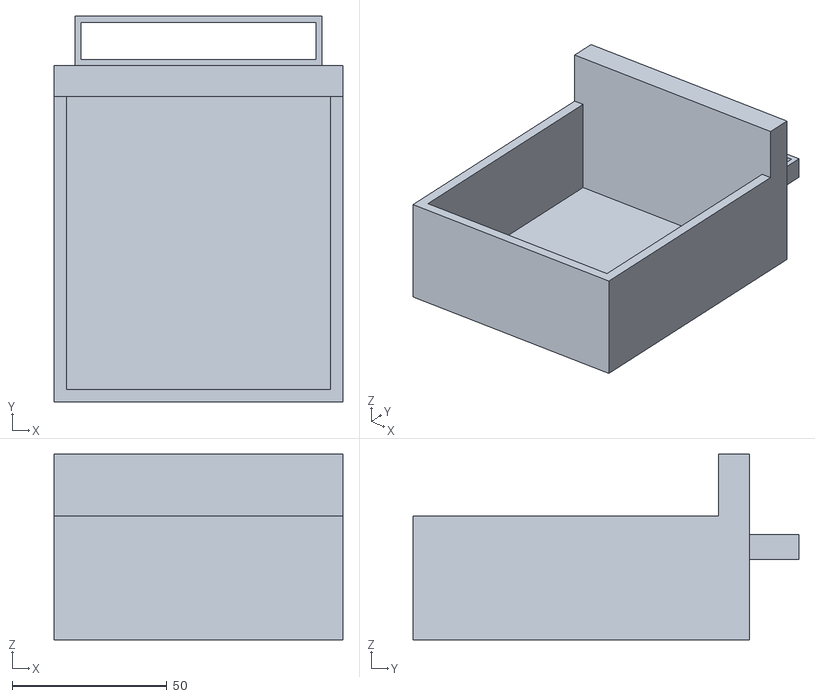
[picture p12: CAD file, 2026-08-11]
simulation/backends/mujoco/assets/meshes/drawer_3_link.stl
93.5 x 124.8 x 60.1

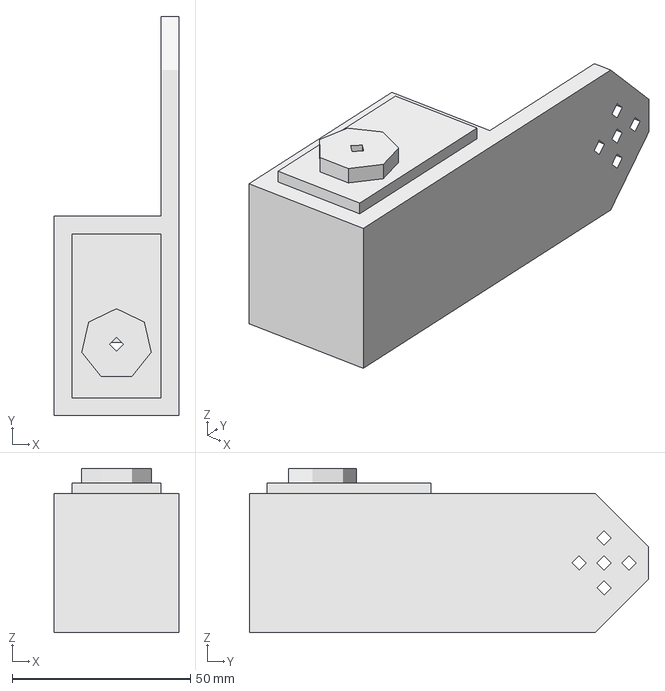
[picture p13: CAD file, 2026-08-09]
cad/assembly/left_arm.FCStd
35.0 x 112.0 x 46.0 mm

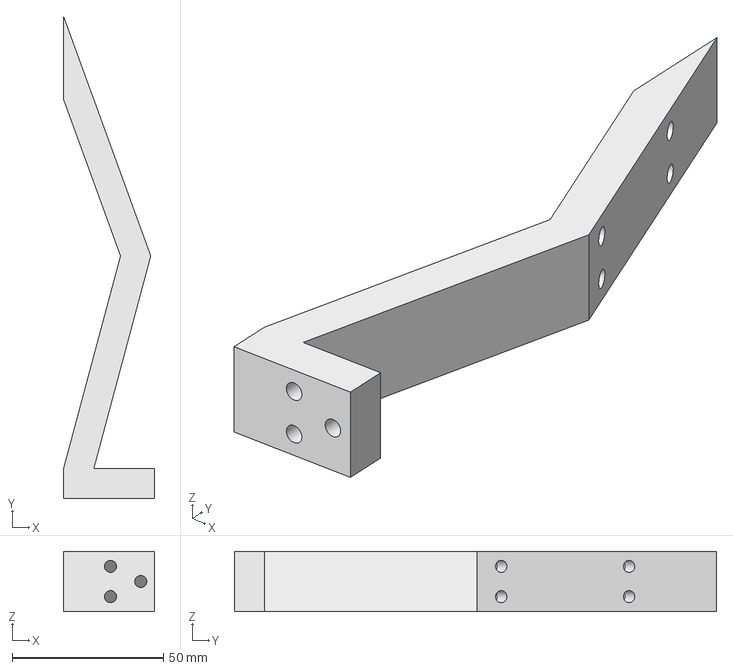
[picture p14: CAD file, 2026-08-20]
cad/parts/arms/eyes/intel_camera_bar.FCStd
30.0 x 159.4 x 20.0 mm

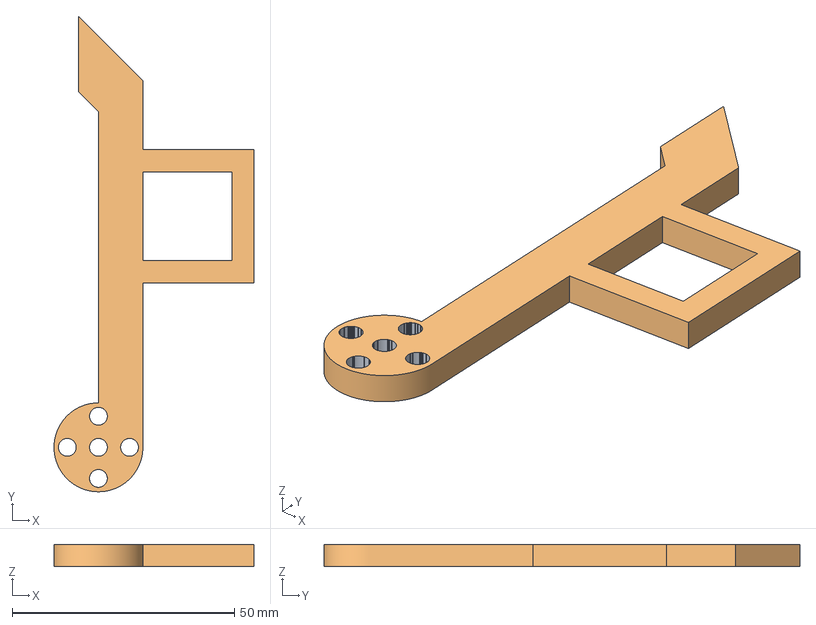
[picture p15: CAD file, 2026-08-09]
cad/parts/arms/fingers/finger_0_leader.FCStd
45.0 x 107.0 x 5.00 mm
Body (Meshed)

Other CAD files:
cad/parts/arms/forearm/forearm_right.FCStd
cad/parts/arms/arm/arm_right.FCStd
cad/parts/arms/forearm/forearm_left.FCStd
cad/parts/arms/hand/hand_right.FCStd
cad/assembly/base.FCStd
cad/assembly/base.stl
cad/assembly/left_hand.FCStd
cad/assembly/left_shoulder.FCStd
cad/assembly/left_shoulder.stl
cad/assembly/right_arm.FCStd
cad/assembly/right_hand.FCStd
cad/assembly/right_shoulder.FCStd
cad/assembly/right_shoulder.stl
cad/parts/arms/eyes/intel_camera_holder.FCStd
cad/parts/arms/head/head_part_1.FCStd
cad/parts/arms/wrist/wrist.FCStd
cad/parts/drawers/drawer.FCStd
cad/parts/drawers/drawer_fixator.FCStd
cad/parts/drawers/drawer_fixator_0.FCStd
cad/parts/drawers/drawer_fixator_1.FCStd
cad/parts/drawers/drawer_fixator_2.FCStd
cad/parts/drawers/drawer_handle.FCStd
simulation/backends/mujoco/assets/meshes/arm_l_link.stl
simulation/backends/mujoco/assets/meshes/arm_r_link.stl
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

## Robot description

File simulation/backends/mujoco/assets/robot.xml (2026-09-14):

<?xml version='1.0' encoding='utf-8'?>
<mujoco model="hepha-robot-cad">
    <compiler angle="radian" autolimits="true" />
    <option timestep="0.002" integrator="implicitfast" cone="elliptic" impratio="10" gravity="0 0 -9.81" />
    <statistic center="-0.15 -0.05 0.35" extent="1.5" />
    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
    <default>
        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
        <joint damping="1.5" armature="0.02" frictionloss="0.05" />
        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
        <position kp="250" dampratio="1" forcerange="-120 120" />
    </default>
    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
    <worldbody>
        <light directional="true" pos="-0.5 0.5 3" dir="0 0 -1" />
        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
        <camera name="front" pos="1.3 -1.6 1.1" xyaxes="0.78 0.63 0 -0.31 0.38 0.87" />
        <camera name="side" pos="-1.7 -0.4 0.9" xyaxes="0.23 -0.97 0 0.45 0.11 0.89" />
        <camera name="top" pos="-0.15 -0.05 2.1" xyaxes="1 0 0 0 1 0" />
        <body name="base_link" pos="0.0 0.0 0.0" euler="-0.0 0.0 -0.0">
            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
            <body name="rack_structure_link" pos="-0.01580200000000003 -0.11589999999999988 0.010031999999999998" euler="-1.2918958832003428e-16 -2.515614676406474e-32 1.8059089196757125e-47">
                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
                <inertial mass="7.284418850265611" pos="0.013542436676072734 -0.35878782749861354 0.19742868693948415" fullinertia="0.05103672988826036 0.11776972189109569 0.0821768645697798 -1.3640046999001993e-08 -1.6878221279155708e-05 -1.0006088180687221e-05" />
            </body>
            <body name="storage_bin_link" pos="0 0 0" euler="0 0 0">
                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
                <body name="storage_bin_center_marker" pos="0 0.1 0.055" quat="1 0 0 0">
                    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
                </body>
            </body>
            <inertial mass="287.26314801093747" pos="8.007987953522093e-05 0.08744546073572491 0.0847762024349828" fullinertia="35.34866560761468 25.357808522367534 53.763140960536376 0.01058122512595603 -0.0013848130361038787 -3.089676744226039" />
            <body name="cnc_x_link" pos="-3.552713678800501e-17 -0.08000000000000004 -1.3322676295501878e-17" euler="-0.0 0.0 3.8453833243485208e-31">
                <joint name="base_link_base_cnc_x_joint" type="slide" axis="3.289960873394836e-31 1.0 0.0" pos="0.36500000000000005 0.14000000000000004 0.305" ref="0" range="-0.1 0.23" />
                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
                <inertial mass="44.560525" pos="-5.1270731008074895e-17 0.295 0.36000792742006515" fullinertia="0.050456894335054514 3.3921732663663056 3.3912918858854155 5.711626727133922e-17 9.13679162484155e-17 -1.3322676295501878e-15" />
                <body name="cnc_y_link" pos="0.034999999999999996 -3.552713678800501e-17 0.0" euler="-0.0 0.0 -0.0">
                    <joint name="cnc_x_link_cnc_x_cnc_y_joint" type="slide" axis="-1.0 3.8453833243485208e-31 0.0" pos="-0.39999999999999997 0.3350000000000001 0.395" ref="0" range="-0.2 0.2" />
                    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
                    <inertial mass="26.13476877913349" pos="7.307244323202329e-32 0.2221073321052037 0.4056836431042875" fullinertia="0.6145857025071058 0.6063585209389988 0.035880779486715975 -5.551115123125786e-17 5.551115123125783e-17 -0.0011881295604192488" />
                    <body name="head_camera_frame" pos="0.0367339366674 -0.0246809926629 0.813347995281" quat="-0.00301242463569 -0.000217037732854 0.0718609260542 0.99741008893">
                        <camera name="head_camera" pos="0 0 0" quat="1 0 0 0" fovy="70" />
                        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
                    </body>
                    <body name="head_link" pos="0.0 -3.552713678800501e-17 -3.552713678800501e-17" euler="-0.0 0.0 -0.0">
                        <joint name="cnc_y_link_cnc_y_head_joint" type="slide" axis="0.0 0.0 -1.0" pos="-0.03999999999999996 0.1850000000000001 0.58" ref="0" range="-0.1 0.14" />
                        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
                        <inertial mass="4.937899994170017" pos="-0.001810199117437663 0.11847927197126139 0.4304442637179299" fullinertia="0.016208491913883738 0.014123788444106 0.01633334456704214 1.936612568613147e-06 0.0009746032114292258 -0.0003206707666744274" />
                        <body name="shoulder_l_link" pos="-0.0025005645751715335 4.0243364196612676e-14 -0.0220000000000004" euler="3.155443620884047e-29 -3.423187659263466e-16 -6.726232628759122e-44">
                            <joint name="head_link_head_shoulder_l_joint" type="hinge" axis="-1.0 3.845383324347848e-31 3.423187659263466e-16" pos="0.08999956457517172 0.07249999999995987 0.45500100000000043" ref="0" range="-1.5707963267948966 1.5707963267948966" />
                            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
                            <inertial mass="0.06086598121195418" pos="0.10093292126462942 0.08906706545511499 0.455000577847961" fullinertia="1.0591637301417267e-05 1.0591637301484921e-05 1.549600110190572e-05 -4.328446823614041e-06 -2.166725489207172e-18 -2.3837630708930725e-18" />
                            <body name="forearm_l_link" pos="7.03421524131631e-05 -0.007930222422767405 0.022000000000000346" euler="6.106226633726722e-16 0.0 1.1777960377692807e-29">
                                <joint name="shoulder_l_link_shoulder_l_forearm_l_joint" type="hinge" axis="-1.232389329660039e-28 -1.0 6.106226633727038e-16" pos="0.11742922242275856 0.10793022242272754 0.433001" ref="0" range="-0.7853981633974483 2.356194490192345" />
                                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
                                <inertial mass="1.322615599621674" pos="0.11951710369968743 0.13029335773842043 0.39068007352086176" fullinertia="0.0015637120607468746 0.0015494687137995733 0.0003509537591931121 4.216008418642167e-06 7.435845734740612e-05 1.9652436448472324e-05" />
                                <body name="arm_l_link" pos="-0.037168754402817465 0.06296170015350813 -2.573120174346096e-05" euler="5.0487097934144756e-27 -5.4206639177323356e-14 3.1554436208826986e-29">
                                    <joint name="forearm_l_link_forearm_l_arm_l_joint" type="hinge" axis="-1.0 4.39259625155287e-29 5.45489579432497e-14" pos="0.18466797682559505 0.06563852226921935 0.35118573120173346" ref="0" range="-2.356194490192345 0.7853981633974483" />
                                    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
                                    <inertial mass="0.7054723805731411" pos="0.17379204040031299 -0.001100927786509496 0.35218239636514764" fullinertia="0.00047945582516766016 0.00017795598639351595 0.000457014912063288 -5.600219300973922e-05 1.2923506167913138e-06 6.602032044605089e-06" />
                                    <body name="wrist_l_link" pos="0.004698911207667765 5.3067069370174026e-05 -0.008162692562710884" euler="-7.099520974836015e-14 5.45489579432497e-14 3.872577005290593e-27">
                                        <joint name="arm_l_link_arm_l_wrist_l_joint" type="hinge" axis="3.587324068671532e-43 -7.038458708498241e-14 1.0" pos="0.16736806561790768 -0.01994454480017819 0.3857564237644528" ref="0" range="-1.5707963267948966 1.5707963267948966" />
                                        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
                                        <inertial mass="0.698313574199002" pos="0.16734866035845536 -0.08071724058435842 0.36542745189706155" fullinertia="0.00045253404319045565 0.0002695392378261154 0.00032074507240269245 -1.7293857477833148e-07 -2.877815320074913e-08 -7.203946742244754e-05" />
                                        <body name="hand_l_link" pos="-0.0008667804615630992 0.005989868261108032 0.0060745008364249545" euler="2.227382159879897e-14 -9.753318261136062e-43 -3.78924492412223e-15">
                                            <joint name="wrist_l_link_wrist_l_hand_l_joint" type="hinge" axis="-3.789244924122195e-15 1.0 4.8110765486183436e-14" pos="0.16816484607947121 -0.11765241306127666 0.36965992292802397" ref="0" range="-1.5707963267948966 1.5707963267948966" />
                                            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

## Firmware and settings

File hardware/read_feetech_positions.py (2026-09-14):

#!/usr/bin/env python3
"""Continuously print positions from STS3215 servos on a Feetech bus."""

from __future__ import annotations

import argparse
import signal
import sys
import time

try:
    from .axes import SERVO_LABELS
    from .calibration import STEPS_PER_REVOLUTION
    from .scan_feetech_ids import find_candidate_ports
except ImportError:  # Direct execution: python hardware/read_feetech_positions.py
    from axes import SERVO_LABELS
    from calibration import STEPS_PER_REVOLUTION
    from scan_feetech_ids import find_candidate_ports


def positive_rate(value: str) -> float:
    rate = float(value)
    if rate <= 0:
        raise argparse.ArgumentTypeError("rate must be greater than zero")
    return rate


def servo_id(value: str) -> int:
    parsed = int(value)
    if not 1 <= parsed <= 252:
        raise argparse.ArgumentTypeError("servo IDs must be between 1 and 252")
    return parsed


def nonnegative_integer(value: str) -> int:
    parsed = int(value)
    if parsed < 0:
        raise argparse.ArgumentTypeError("retries cannot be negative")
    return parsed


def parse_args() -> argparse.Namespace:
    parser = argparse.ArgumentParser(
        description="Continuously read all detected Feetech STS3215 positions."
    )
    parser.add_argument(
        "--port",
        help="USB serial port. If omitted, connected USB serial ports are probed.",
    )
    parser.add_argument(
        "--ids",
        type=servo_id,
        nargs="+",
        help="Expected servo IDs, for example: --ids 1 3",
    )
    parser.add_argument(
        "--rate",
        type=positive_rate,
        default=10.0,
        help="Reads per second (default: 10).",
    )
    parser.add_argument(
        "--retries",
        type=nonnegative_integer,
        default=2,
        help="Retries after a failed serial read (default: 2).",
    )
    parser.add_argument(
        "--format",
        dest="output_format",
        choices=("table", "csv"),
        default="table",
        help="Terminal output format (default: table).",
    )
    return parser.parse_args()


def position_degrees(raw: int) -> float:
    return raw * 360.0 / STEPS_PER_REVOLUTION


def format_live_table(
    *,
    port: str,
    baudrate: int,
    elapsed: float,
    ids: list[int],
    raw_positions: dict[int, int],
) -> str:
    rows = [
        "Feetech STS3215 bus monitor",
        f"Port: {port}",
        f"Baud: {baudrate:,}   Servos: {len(ids)}   Elapsed: {elapsed:8.1f} s",
        "",
        " ID  Robot element          Raw   Position",
        "---  ------------------  ------  ---------",
    ]
    for motor_id in ids:
        raw = raw_positions[motor_id]
        label = SERVO_LABELS.get(motor_id, "unmapped servo")
        rows.append(f"{motor_id:>3}  {label:<18}  {raw:>6}  {position_degrees(raw):>8.2f}°")
    rows.extend(("", "Press Ctrl+C to stop. Use --format csv for logging."))
    return "\n".join(rows)


def scan_for_bus(bus_class: type, requested_port: str | None) -> tuple[str, int, list[int]]:
    ports = [requested_port] if requested_port else find_candidate_ports()
    if not ports:
        raise RuntimeError("No USB serial ports were detected.")

    matches: list[tuple[str, int, list[int]]] = []
    for port in ports:
        print(f"Scanning {port}...", file=sys.stderr)
        try:
            results = bus_class.scan_port(port)
        except Exception as exc:
            print(f"  Skipped {port}: {exc}", file=sys.stderr)
            continue
        for baudrate, ids in results.items():
            if ids:
                matches.append((port, baudrate, sorted(ids)))

    if not matches:
        raise RuntimeError(
            "No servos responded. Check the correct external servo power supply, "
            "USB, and the 3-pin bus cables."
        )
    if len(matches) > 1:
        descriptions = ", ".join(
            f"{port} at {baudrate} baud (IDs {ids})" for port, baudrate, ids in matches
        )
        raise RuntimeError(
            f"More than one responding motor bus was found: {descriptions}. Select one with --port."
        )
    return matches[0]


def main() -> int:
    args = parse_args()

    try:
        from lerobot.motors import Motor, MotorNormMode
        from lerobot.motors.feetech import FeetechMotorsBus
    except ImportError:
        print(
            'Install dependencies with: python -m pip install "lerobot[feetech]"',
            file=sys.stderr,
        )
        return 2

    try:
        port, baudrate, detected_ids = scan_for_bus(FeetechMotorsBus, args.port)
    except RuntimeError as exc:
        print(exc, file=sys.stderr)
        return 1

    if args.ids:
        expected_ids = sorted(set(args.ids))
        missing = sorted(set(expected_ids) - set(detected_ids))
        unexpected = sorted(set(detected_ids) - set(expected_ids))
        if missing or unexpected:
            print(
                f"ID check failed: expected {expected_ids}, detected {detected_ids}."
                + (f" Missing: {missing}." if missing else "")
                + (f" Unexpected: {unexpected}." if unexpected else ""),
                file=sys.stderr,
            )
            return 1
        ids = expected_ids
    else:
        ids = detected_ids

    motors = {
        f"servo_{motor_id}": Motor(
            id=motor_id,
            model="sts3215",
            norm_mode=MotorNormMode.DEGREES,
        )
        for motor_id in ids
    }
    bus = FeetechMotorsBus(port=port, motors=motors)

    try:
        bus.connect(handshake=False)
        bus.set_baudrate(baudrate)
        for motor_id in ids:
            if bus.ping(motor_id, num_retry=args.retries) is None:
                raise RuntimeError(f"Servo ID {motor_id} stopped responding.")

        print(f"Reading IDs {ids} on {port} at {baudrate} baud.")
        if args.output_format == "csv":
            print("Press Ctrl+C to stop.")
            print("time_s," + ",".join(f"id_{motor_id}_raw,id_{motor_id}_deg" for motor_id in ids))

        period = 1.0 / args.rate
        start = time.monotonic()
        next_read = start
        while True:
            positions = bus.sync_read("Present_Position", normalize=False, num_retry=args.retries)
            elapsed = time.monotonic() - start
            raw_positions = {motor_id: int(positions[f"servo_{motor_id}"]) for motor_id in ids}
            if args.output_format == "table":
                table = format_live_table(
                    port=port,
                    baudrate=baudrate,
                    elapsed=elapsed,
                    ids=ids,
                    raw_positions=raw_positions,
                )
                print(f"\033[2J\033[H{table}", end="", flush=True)
            else:
                values = []
                for motor_id in ids:
                    raw = raw_positions[motor_id]
                    values.extend((str(raw), f"{position_degrees(raw):.3f}"))
                print(f"{elapsed:.3f}," + ",".join(values), flush=True)

            next_read += period
            time.sleep(max(0.0, next_read - time.monotonic()))
    except KeyboardInterrupt:
        # Ignore repeated Ctrl+C presses while the serial port is being closed.
        signal.signal(signal.SIGINT, signal.SIG_IGN)
        print("\nStopped.")
    except Exception as exc:
        print(f"\nPosition reading failed: {exc}", file=sys.stderr)
        return 1
    finally:
        if bus.is_connected:
            # This monitor never enables torque, so closing the port is sufficient.
            bus.disconnect(disable_torque=False)

    return 0


if __name__ == "__main__":
    raise SystemExit(main())

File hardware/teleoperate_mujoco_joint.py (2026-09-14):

#!/usr/bin/env python3
"""Drive one or more MuJoCo joints from calibrated physical Feetech servos."""

from __future__ import annotations

import argparse
import signal
import sys
import time
from pathlib import Path

try:
    from .feetech_leader import FeetechLeader, configure_cnc_start_pose
    from .read_feetech_positions import nonnegative_integer, servo_id
except ImportError:  # Direct execution: python hardware/teleoperate_mujoco_joint.py
    from feetech_leader import FeetechLeader, configure_cnc_start_pose
    from read_feetech_positions import nonnegative_integer, servo_id


def smoothing_factor(value: str) -> float:
    parsed = float(value)
    if not 0 < parsed <= 1:
        raise argparse.ArgumentTypeError("smoothing must be greater than 0 and at most 1")
    return parsed


def positive_integer(value: str) -> int:
    parsed = int(value)
    if parsed <= 0:
        raise argparse.ArgumentTypeError("value must be greater than zero")
    return parsed


def selected_servo_ids(single_id: int | None, multiple_ids: list[int] | None) -> list[int]:
    """Resolve the backward-compatible --id and multi-axis --ids options."""
    if multiple_ids:
        return sorted(set(multiple_ids))
    return [2 if single_id is None else single_id]


def parse_args() -> argparse.Namespace:
    parser = argparse.ArgumentParser(description=__doc__)
    ids = parser.add_mutually_exclusive_group()
    ids.add_argument(
        "--id",
        type=servo_id,
        help="One calibrated servo ID (default: 2, left shoulder).",
    )
    ids.add_argument(
        "--ids",
        type=servo_id,
        nargs="+",
        help="One or more calibrated servo IDs, for example: --ids 2 4.",
    )
    parser.add_argument(
        "--calibration",
        type=Path,
        default=Path("hardware/feetech_calibration.json"),
        help="Calibration JSON path (default: hardware/feetech_calibration.json).",
    )
    parser.add_argument("--port", help="Override the serial port saved in the calibration file.")
    parser.add_argument("--fps", type=positive_integer, default=30)
    parser.add_argument(
        "--smoothing",
        type=smoothing_factor,
        default=0.25,
        help="New-sample weight for exponential smoothing (default: 0.25; 1 disables smoothing).",
    )
    parser.add_argument(
        "--retries",
        type=nonnegative_integer,
        default=2,
        help="Retries after a failed serial operation (default: 2).",
    )
    parser.add_argument("--debug", action="store_true", help="Show MuJoCo debug geometry.")
    return parser.parse_args()


def main() -> int:
    args = parse_args()
    servo_ids = selected_servo_ids(args.id, args.ids)

    from simulation.view import _ensure_mjpython_on_macos

    _ensure_mjpython_on_macos("hardware.teleoperate_mujoco_joint")

    try:
        import mujoco

        from simulation.backends.mujoco import ACTUATOR_NAMES, MujocoBackend
        from simulation.base import SimulationConfig

        leader = FeetechLeader(
            calibration_path=args.calibration,
            servo_ids=servo_ids,
            port=args.port,
            retries=args.retries,
            smoothing=args.smoothing,
        )
        config = SimulationConfig(fps=args.fps, render=False, viewer=False, debug=args.debug)
        with MujocoBackend(config) as backend:
            leader.validate_mujoco_ranges(
                ACTUATOR_NAMES,
                backend.control_low,
                backend.control_high,
            )
            with leader:
                print("\nPhysical servos -> MuJoCo multi-axis test")
                for servo in leader.servos:
                    print(f"ID {servo.servo_id}: {servo.label} -> {servo.actuator}")
                print(f"Port: {leader.port}   Baud: {leader.baudrate:,}")
                print("The physical servos will only be read; no commands are sent to them.")
                print("Selected arm actuators follow the servos; others remain at home.")
                print("MuJoCo CNC start pose: cnc_x=0 m, cnc_y=0 m, head_z=-0.1 m (minimum).")
                input(
                    "Support the selected physical axes, then press ENTER to disable "
                    "their torque and open MuJoCo: "
                )
                leader.disable_torque()

                base_action = backend.home_action()
                configure_cnc_start_pose(base_action, backend.control_low, ACTUATOR_NAMES)
                leader.reset_filter()
                action = leader.read_action(base_action, ACTUATOR_NAMES)
                backend.data.qpos[backend.qpos_ids] = action
                dof_ids = backend.model.jnt_dofadr[backend.joint_ids].astype(int)
                backend.data.qvel[dof_ids] = 0.0
                backend.send_action(action)
                mujoco.mj_forward(backend.model, backend.data)
                backend.open_viewer(debug=args.debug)

                actuator_indices = {
                    servo.servo_id: ACTUATOR_NAMES.index(servo.actuator) for servo in leader.servos
                }
                print("Move the physical axes slowly. Close the viewer or press Ctrl+C to stop.")
                period = 1.0 / args.fps
                previous_line_width = 0
                while backend.viewer_is_running():
                    started = time.perf_counter()
                    action = leader.read_action(base_action, ACTUATOR_NAMES)
                    backend.send_action(action)
                    backend.step()
                    simulated_positions = backend.joint_positions()
                    status = " | ".join(
                        f"ID {servo.servo_id:>2} "
                        f"raw={leader.last_raw_positions[servo.servo_id]:>4} "
                        f"target={leader.last_targets[servo.actuator]:+.3f} "
                        "sim="
                        f"{float(simulated_positions[actuator_indices[servo.servo_id]]):+.3f} "
                        "rad"
                        for servo in leader.servos
                    )
                    print(f"\r{status:<{previous_line_width}}", end="", flush=True)
                    previous_line_width = max(previous_line_width, len(status))
                    time.sleep(max(0.0, period - (time.perf_counter() - started)))
                print()
        return 0
    except KeyboardInterrupt:
        signal.signal(signal.SIGINT, signal.SIG_IGN)
        print("\nStopped.")
        return 130
    except Exception as exc:
        print(f"\nTeleoperation failed: {exc}", file=sys.stderr)
        return 1


if __name__ == "__main__":
    raise SystemExit(main())

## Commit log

2026-08-09 restructure the project, initial commit
    [arm_l_link.stl, arm_r_link.stl, base.FCStd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]
2026-08-11 ik(recording): started cleaner IK controller recording
    [drawer_1_link.stl, drawer_2_link.stl, drawer_3_link.stl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]
2026-08-14 ik(recording): base IK working
    [robot.xml]
2026-08-16 update(cad): reorganize files
    [head_part_0.FCStd, head_part_1.FCStd, servo_motor_attach.FCStd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]
2026-08-16 fix(act): Preserve phase targets through ACT preprocessing
    [arm_left.FCStd, arm_right.FCStd, drawer_fixator.FCStd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]
2026-08-20 feat(awr): Add ACT advantage-weighted regression training
    [intel_camera_bar.FCStd, top_cnc_z_fixator.FCStd]
2026-08-21 fix(awr): Fix AWR dataset multiprocessing serialization
    [top_cnc_z_fixator.FCStd]
2026-09-14 fix(simulation): Fix Mujoco simulation
    [drawer.FCStd, drawer_fixator.FCStd, drawer_fixator_0.FCStd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]
